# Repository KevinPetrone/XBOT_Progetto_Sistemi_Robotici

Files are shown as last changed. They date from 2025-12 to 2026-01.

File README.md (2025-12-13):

# XBOT_Progetto_Sistemi_Robotici
<!DOCTYPE html>
<html lang="it">
<head>
    <meta charset="UTF-8">
    <meta name="viewport" content="width=device-width, initial-scale=1.0">
    <title>Relazione Progetto Tris Robotico</title>
    <style>
        @page {
            size: A4;
            margin: 2cm;
        }
        
        body {
            font-family: 'Times New Roman', serif;
            font-size: 12pt;
            line-height: 1.6;
            color: #000;
            margin: 0;
            padding: 2cm;
            max-width: 21cm;
            margin: auto;
            background: white;
        }
        
        .page-break {
            page-break-before: always;
            margin-top: 2cm;
        }
        
        .title-page {
            text-align: center;
            margin-top: 4cm;
        }
        
        .title-page h1 {
            font-size: 18pt;
            margin-bottom: 0.5cm;
            font-weight: bold;
            text-transform: uppercase;
        }
        
        .title-page h2 {
            font-size: 16pt;
            margin-bottom: 2cm;
            font-weight: bold;
            text-transform: uppercase;
        }
        
        .title-page .project-title {
            font-size: 24pt;
            margin: 3cm 0;
            color: #000080;
            font-weight: bold;
        }
        
        .info-box {
            text-align: left;
            margin: 2cm auto;
            width: 70%;
            font-size: 12pt;
            line-height: 2;
        }
        
        .info-box strong {
            display: inline-block;
            width: 180px;
        }
        
        .toc {
            margin-top: 2cm;
        }
        
        .toc h2 {
            text-align: center;
            font-size: 18pt;
            margin-bottom: 1.5cm;
            font-weight: bold;
            text-transform: uppercase;
        }
        
        .toc-item {
            margin-bottom: 0.4cm;
            display: flex;
            justify-content: space-between;
            font-size: 12pt;
            padding: 0.2cm 0;
        }
        
        .toc-item.main {
            font-weight: bold;
            margin-top: 0.8cm;
        }
        
        .toc-item.sub {
            margin-left: 1cm;
            font-weight: normal;
        }
        
        .toc-item span:first-child {
            flex-grow: 1;
        }
        
        .toc-item span:last-child {
            margin-left: 1cm;
        }
        
        .chapter {
            margin-top: 1.5cm;
        }
        
        .chapter h2 {
            font-size: 16pt;
            color: #000080;
            border-bottom: 2px solid #000080;
            padding-bottom: 0.3cm;
            margin-bottom: 0.8cm;
            font-weight: bold;
            text-transform: uppercase;
        }
        
        .chapter h3 {
            font-size: 14pt;
            color: #000060;
            margin-top: 1cm;
            margin-bottom: 0.5cm;
            font-weight: bold;
        }
        
        .chapter h4 {
            font-size: 12pt;
            color: #000040;
            margin-top: 0.8cm;
            margin-bottom: 0.4cm;
            font-weight: bold;
        }
        
        .theory {
            background-color: #f0f8ff;
            padding: 0.6cm;
            border-left: 4px solid #4169e1;
            margin: 0.8cm 0;
        }
        
        .code-block {
            background-color: #f5f5f5;
            padding: 0.5cm;
            border: 1px solid #ddd;
            margin: 0.8cm 0;
            font-family: 'Courier New', monospace;
            font-size: 10pt;
            overflow-x: auto;
            white-space: pre-wrap;
            word-wrap: break-word;
        }
        
        .note {
            background-color: #fffacd;
            padding: 0.6cm;
            border: 2px solid #daa520;
            margin: 0.8cm 0;
        }
        
        .highlight {
            background-color: #fff8dc;
            padding: 0.6cm;
            border-left: 4px solid #ffa500;
            margin: 0.8cm 0;
        }
        
        table {
            width: 100%;
            border-collapse: collapse;
            margin: 1cm 0;
            font-size: 11pt;
        }
        
        th, td {
            border: 1px solid #333;
            padding: 0.4cm;
            text-align: left;
        }
        
        th {
            background-color: #4169e1;
            color: white;
            font-weight: bold;
        }
        
        tr:nth-child(even) {
            background-color: #f9f9f9;
        }
        
        ul, ol {
            margin: 0.5cm 0;
            padding-left: 1.5cm;
        }
        
        li {
            margin-bottom: 0.3cm;
        }
        
        .formula {
            text-align: center;
            margin: 0.8cm 0;
            font-size: 13pt;
            font-style: italic;
        }
        
        p {
            text-align: justify;
            margin-bottom: 0.5cm;
        }
        
        @media print {
            body {
                padding: 0;
            }
            .page-break {
                page-break-before: always;
            }
        }
    </style>
</head>
<body>

    <!-- PAGINA DEL TITOLO -->
    <div class="title-page">
        <h1>Università degli Studi di Palermo</h1>
        <h2>Facoltà di Ingegneria</h2>
        
        <div class="project-title">
            Progetto Esame<br>Sistemi Robotici
        </div>
        
        <div class="info-box">
            <div><strong>Sviluppatori:</strong> Petrone Kevin, Di Peri Marta, Daniele Bagarona</div>
            <div><strong>Matricola:</strong> 0774409, 0774023, 077XXXX</div>
            <div style="margin-top: 0.8cm;"><strong>Docente:</strong> Prof. Filippo D'Ippolito</div>
            <div><strong>Corso:</strong> Ingegneria Robotica</div>
            <div><strong>Anno Accademico:</strong> 2025/2026</div>
            <div><strong>Data:</strong> Dicembre 2025</div>
        </div>
    </div>

    <!-- INDICE -->
    <div class="page-break">
        <div class="toc">
            <h2>Indice</h2>
            
            <div class="toc-item main">
                <span>1. INTRODUZIONE</span>
                <span>3</span>
            </div>
            <div class="toc-item sub">
                <span>1.1 Obiettivi del Progetto</span>
                <span>3</span>
            </div>
            <div class="toc-item sub">
                <span>1.2 Specifiche Tecniche</span>
                <span>4</span>
            </div>
            
            <div class="toc-item main">
                <span>2. ARCHITETTURA DEL SISTEMA</span>
                <span>5</span>
            </div>
            <div class="toc-item sub">
                <span>2.1 Hardware Utilizzato</span>
                <span>5</span>
            </div>
            <div class="toc-item sub">
                <span>2.2 Software e Librerie</span>
                <span>6</span>
            </div>
            <div class="toc-item sub">
                <span>2.3 Schema di Comunicazione</span>
                <span>7</span>
            </div>
            
            <div class="toc-item main">
                <span>3. MODELLO CINEMATICO</span>
                <span>8</span>
            </div>
            <div class="toc-item sub">
                <span>3.1 Cinematica Diretta</span>
                <span>8</span>
            </div>
            <div class="toc-item sub">
                <span>3.2 Cinematica Inversa</span>
                <span>9</span>
            </div>
            <div class="toc-item sub">
                <span>3.3 Workspace del Robot</span>
                <span>11</span>
            </div>
            <div class="toc-item sub">
                <span>3.4 Cinematica Differenziale</span>
                <span>12</span>
            </div>
            
            <div class="toc-item main">
                <span>4. COMUNICAZIONE E INTEGRAZIONE</span>
                <span>13</span>
            </div>
            <div class="toc-item sub">
                <span>4.1 Protocollo di Comunicazione Seriale</span>
                <span>13</span>
            </div>
            <div class="toc-item sub">
                <span>4.2 Gestione Interpolazione Hardware</span>
                <span>14</span>
            </div>
            
            <div class="toc-item main">
                <span>5. PIANIFICAZIONE DEL MOTO</span>
                <span>15</span>
            </div>
            <div class="toc-item sub">
                <span>5.1 Traiettorie Lineari</span>
                <span>15</span>
            </div>
            <div class="toc-item sub">
                <span>5.2 Generazione Simboli X e O</span>
                <span>16</span>
            </div>
            <div class="toc-item sub">
                <span>5.3 Coordinamento Movimenti Penna</span>
                <span>17</span>
            </div>
            
            <div class="toc-item main">
                <span>6. SIMULAZIONE CON ROBOTICS TOOLBOX</span>
                <span>18</span>
            </div>
            <div class="toc-item sub">
                <span>6.1 Modellazione del Robot</span>
                <span>18</span>
            </div>
            <div class="toc-item sub">
                <span>6.2 Visualizzazione 3D e Video</span>
                <span>19</span>
            </div>
            
            <div class="toc-item main">
                <span>7. LOGICA DI GIOCO E ALGORITMO AI</span>
                <span>20</span>
            </div>
            <div class="toc-item sub">
                <span>7.1 Rappresentazione dello Stato</span>
                <span>20</span>
            </div>
            <div class="toc-item sub">
                <span>7.2 Algoritmo Euristico Minimax</span>
                <span>21</span>
            </div>
            
            <div class="toc-item main">
                <span>8. TESTING E VALIDAZIONE</span>
                <span>22</span>
            </div>
            <div class="toc-item sub">
                <span>8.1 Verifica Cinematica</span>
                <span>22</span>
            </div>
            <div class="toc-item sub">
                <span>8.2 Accuratezza Posizionamento</span>
                <span>23</span>
            </div>
            
            <div class="toc-item main">
                <span>9. CONCLUSIONI</span>
                <span>24</span>
            </div>
            <div class="toc-item sub">
                <span>9.1 Risultati Ottenuti</span>
                <span>24</span>
            </div>
            <div class="toc-item sub">
                <span>9.2 Sviluppi Futuri</span>
                <span>25</span>
            </div>
            
            <div class="toc-item main">
                <span>BIBLIOGRAFIA</span>
                <span>26</span>
            </div>
        </div>
    </div>

    <!-- CAPITOLO 1: INTRODUZIONE -->
    <div class="page-break">
        <div class="chapter">
            <h2>1. Introduzione</h2>
            
            <h3>1.1 Obiettivi del Progetto</h3>
            
            <p>Il presente progetto si inserisce nell'ambito dei sistemi robotici interattivi e ha come obiettivo la realizzazione di un robot antropomorfo a 3 gradi di libertà capace di giocare autonomamente al gioco del tris contro un utente umano. Il sistema integra componenti hardware (Arduino, servomotori, display OLED, buzzer) con un ambiente di simulazione e controllo realizzato in MATLAB utilizzando la Robotics Toolbox.</p>
            
            <div class="highlight">
                <strong>Obiettivi principali:</strong>
                <ul>
                    <li><strong>Progettazione cinematica:</strong> Sviluppo del modello cinematico diretto e inverso per un manipolatore planare 2R + prismatico</li>
                    <li><strong>Controllo in tempo reale:</strong> Implementazione di un sistema di controllo Arduino per la gestione coordinata di tre servomotori con interpolazione fluida dei movimenti</li>
                    <li><strong>Intelligenza Artificiale:</strong> Sviluppo di un algoritmo di gioco basato su logica euristica per garantire mosse competitive</li>
                    <li><strong>Interfaccia utente:</strong> Integrazione di feedback visivo (OLED) e sonoro (buzzer) per migliorare l'esperienza interattiva</li>
                    <li><strong>Simulazione e validazione:</strong> Utilizzo di MATLAB per simulare, validare e registrare l'intero processo di gioco</li>
                </ul>
            </div>
            
            <p>Il progetto rappresenta un esempio concreto di integrazione tra teoria della robotica (cinematica, pianificazione del moto) e applicazione pratica, dimostrando come concetti matematici complessi possano essere tradotti in un sistema funzionante e interattivo.</p>
            
            <h3>1.2 Specifiche Tecniche</h3>
            
            <p>Il robot realizzato presenta le seguenti caratteristiche tecniche:</p>
            
            <table>
                <tr>
                    <th>Componente</th>
                    <th>Specifica</th>
                    <th>Valore/Modello</th>
                </tr>
                <tr>
                    <td>Microcontrollore</td>
                    <td>Arduino Uno</td>
                    <td>ATmega328P</td>
                </tr>
                <tr>
                    <td>Servomotore 1 (base)</td>
                    <td>Rotazione base</td>
                    <td>0° - 180°, Pin 9</td>
                </tr>
                <tr>
                    <td>Servomotore 2 (braccio)</td>
                    <td>Rotazione braccio</td>
                    <td>0° - 180°, Pin 10</td>
                </tr>
                <tr>
                    <td>Servomotore 3 (penna)</td>
                    <td>Alzata/abbassata penna</td>
                    <td>90° - 180°, Pin 11</td>
                </tr>
                <tr>
                    <td>Display</td>
                    <td>OLED SSD1306</td>
                    <td>128x64 pixel, I2C</td>
                </tr>
                <tr>
                    <td>Audio</td>
                    <td>Buzzer piezoelettrico</td>
                    <td>Pin 3</td>
                </tr>
                <tr>
                    <td>Comunicazione</td>
                    <td>Seriale</td>
                    <td>115200 baud</td>
                </tr>
                <tr>
                    <td>Lunghezza link 1</td>
                    <td>L₁</td>
                    <td>2.5 unità</td>
                </tr>
                <tr>
                    <td>Lunghezza link 2</td>
                    <td>L₂</td>
                    <td>2.0 unità</td>
                </tr>
                <tr>
                    <td>Workspace</td>
                    <td>Piano XY</td>
                    <td>[-1, 5] × [-3, 5]</td>
                </tr>
                <tr>
                    <td>Griglia tris</td>
                    <td>Dimensione cella</td>
                    <td>0.9 × 0.9 unità</td>
                </tr>
                <tr>
                    <td>Tempo interpolazione</td>
                    <td>Movimento fluido</td>
                    <td>500 ms</td>
                </tr>
            </table>
            
            <div class="note">
                <strong>Nota:</strong> Il sistema è progettato per operare su un piano di lavoro orizzontale. Le coordinate sono espresse in unità adimensionali proporzionali alle lunghezze fisiche dei link del robot.
            </div>
        </div>
    </div>

    <!-- CAPITOLO 2: ARCHITETTURA DEL SISTEMA -->
    <div class="page-break">
        <div class="chapter">
            <h2>2. Architettura del Sistema</h2>
            
            <h3>2.1 Hardware Utilizzato</h3>
            
            <p>L'architettura hardware del sistema è composta da diversi moduli interconnessi che collaborano per realizzare le funzionalità del robot:</p>
            
            <h4>2.1.1 Sistema di Attuazione</h4>
            
            <div class="theory">
                <strong>Servomotori:</strong>
                <ul>
                    <li><strong>Servo 1 (Base):</strong> Montato sul pin 9, controlla la rotazione alla base del robot. Riceve comandi in gradi da 0° a 180° e posiziona il primo link del manipolatore.</li>
                    <li><strong>Servo 2 (Braccio):</strong> Montato sul pin 10, controlla l'angolo del secondo link. Opera in modalità invertita (180° - angolo calcolato) per compensare l'orientamento meccanico.</li>
                    <li><strong>Servo 3 (Penna):</strong> Montato sul pin 11, gestisce l'alzata e l'abbassata della penna tramite un giunto prismatico simulato. Range operativo: 90° (penna su) - 180° (penna giù).</li>
                </ul>
            </div>
            
            <h4>2.1.2 Sistema di Interfaccia</h4>
            
            <p><strong>Display OLED SSD1306:</strong> Display grafico da 128×64 pixel con comunicazione I2C (indirizzo 0x3C). Utilizzato per visualizzare:</p>
            <ul>
                <li>Logo del sistema all'avvio ("XBOT v1.0")</li>
                <li>Messaggi di stato durante il gioco</li>
                <li>Indicazioni del turno corrente</li>
                <li>Messaggi di vittoria/sconfitta/pareggio con animazioni di scorrimento</li>
            </ul>
            
            <p><strong>Buzzer Piezoelettrico:</strong> Connesso al pin 3, genera feedback sonoro per eventi di gioco:</p>
            <ul>
                <li>Melodia di avvio (4 note crescenti)</li>
                <li>Suono per ogni cambio turno</li>
                <li>Melodia di vittoria (7 note festose)</li>
                <li>Melodia game over (4 note discendenti)</li>
            </ul>
            
            <h4>2.1.3 Schema Elettrico</h4>
            
            <div class="code-block">Arduino Uno
    │
    ├─ Pin 9  → Servo 1 (Base)
    ├─ Pin 10 → Servo 2 (Braccio)
    ├─ Pin 11 → Servo 3 (Penna)
    ├─ Pin 3  → Buzzer
    ├─ SDA    → OLED SDA (Display I2C)
    ├─ SCL    → OLED SCL (Display I2C)
    └─ USB    → Comunicazione Seriale con MATLAB</div>
            
            <h3>2.2 Software e Librerie</h3>
            
            <h4>2.2.1 Ambiente Arduino</h4>
            
            <p>Il firmware Arduino è implementato utilizzando le seguenti librerie:</p>
            
            <table>
                <tr>
                    <th>Libreria</th>
                    <th>Versione</th>
                    <th>Funzione</th>
                </tr>
                <tr>
                    <td>Servo.h</td>
                    <td>Standard</td>
                    <td>Controllo servomotori tramite segnale PWM</td>
                </tr>
                <tr>
                    <td>Wire.h</td>
                    <td>Standard</td>
                    <td>Comunicazione I2C per display OLED</td>
                </tr>
                <tr>
                    <td>Adafruit_GFX.h</td>
                    <td>1.x</td>
                    <td>Libreria grafica di base per display</td>
                </tr>
                <tr>
                    <td>Adafruit_SSD1306.h</td>
                    <td>2.x</td>
                    <td>Driver specifico per display SSD1306</td>
                </tr>
            </table>
            
            <h4>2.2.2 Ambiente MATLAB</h4>
            
            <p>Il sistema di controllo e simulazione utilizza:</p>
            
            <table>
                <tr>
                    <th>Toolbox/Funzione</th>
                    <th>Utilizzo</th>
                </tr>
                <tr>
                    <td>Robotics Toolbox</td>
                    <td>Modellazione cinematica, simulazione 3D del robot</td>
                </tr>
                <tr>
                    <td>SerialPort</td>
                    <td>Comunicazione bidirezionale con Arduino</td>
                </tr>
                <tr>
                    <td>VideoWriter</td>
                    <td>Registrazione video della simulazione</td>
                </tr>
                <tr>
                    <td>Link/SerialLink</td>
                    <td>Definizione della struttura cinematica del robot</td>
                </tr>
            </table>
            
            <div class="highlight">
                <strong>Flusso di lavoro software:</strong>
                <ol>
                    <li>MATLAB inizializza la connessione seriale con Arduino (115200 baud)</li>
                    <li>Arduino entra in modalità ascolto e inizializza i servomotori</li>
                    <li>MATLAB simula il robot e calcola la cinematica inversa per ogni posizione target</li>
                    <li>I comandi vengono inviati ad Arduino nel formato: <code>A,angolo1,angolo2,angolo3</code></li>
                    <li>Arduino interpola i movimenti in modo fluido e aggiorna i servomotori</li>
                    <li>Il feedback viene visualizzato sul display OLED e tramite suoni</li>
                    <li>MATLAB registra ogni frame della simulazione per generare il video finale</li>
                </ol>
            </div>
            
            <h3>2.3 Schema di Comunicazione</h3>
            
            <p>Il protocollo di comunicazione seriale tra MATLAB e Arduino è basato su messaggi testuali terminati dal carattere newline (\n). I comandi supportati sono:</p>
            
            <table>
                <tr>
                    <th>Comando</th>
                    <th>Formato</th>
                    <th>Esempio</th>
                    <th>Descrizione</th>
                </tr>
                <tr>
                    <td>Posizione</td>
                    <td>A,θ₁,θ₂,z</td>
                    <td>A,90,120,180</td>
                    <td>Imposta angoli servomotori (gradi)</td>
                </tr>
                <tr>
                    <td>Suono mossa</td>
                    <td>MOVE</td>
                    <td>MOVE</td>
                    <td>Riproduce suono cambio turno</td>
                </tr>
                <tr>
                    <td>Vittoria</td>
                    <td>WIN</td>
                    <td>WIN</td>
                    <td>Riproduce melodia di vittoria</td>
                </tr>
                <tr>
                    <td>Sconfitta</td>
                    <td>LOSE</td>
                    <td>LOSE</td>
                    <td>Riproduce melodia game over</td>
                </tr>
                <tr>
                    <td>Messaggio</td>
                    <td>MSG,testo,x,y,size</td>
                    <td>MSG,Turno,0,25,2</td>
                    <td>Visualizza testo su display OLED</td>
                </tr>
            </table>
            
            <div class="note">
                <strong>Timing critico:</strong> Arduino implementa un sistema di interpolazione non bloccante che consente di ricevere nuovi comandi durante l'esecuzione di un movimento. Questo garantisce fluidità e reattività del sistema senza accumulo di ritardi.
            </div>
        </div>
    </div>

    <!-- CAPITOLO 3: MODELLO CINEMATICO -->
    <div class="page-break">
        <div class="chapter">
            <h2>3. Modello Cinematico</h2>
            
            <h3>3.1 Cinematica Diretta</h3>
            
            <p>Il robot è modellato come una catena cinematica seriale composta da tre link secondo i parametri di Denavit-Hartenberg:</p>
            
            <table>
                <tr>
                    <th>Link</th>
                    <th>aᵢ</th>
                    <th>αᵢ</th>
                    <th>dᵢ</th>
                    <th>θᵢ</th>
                    <th>Tipo</th>
                </tr>
                <tr>
                    <td>1</td>
                    <td>L₁</td>
                    <td>0</td>
                    <td>0</td>
                    <td>θ₁ (var)</td>
                    <td>Rotoidale</td>
                </tr>
                <tr>
                    <td>2</td>
                    <td>L₂</td>
                    <td>0</td>
                    <td>0</td>
                    <td>θ₂ (var)</td>
                    <td>Rotoidale</td>
                </tr>
                <tr>
                    <td>3</td>
                    <td>0</td>
                    <td>π/2</td>
                    <td>d₃</td>
                    <td>0</td>
                    <td>Prismatico</td>
                </tr>
            </table>
            
            <div class="theory">
                <strong>Equazioni della cinematica diretta (piano XY):</strong>
                <p>Per i primi due link (manipolatore planare 2R):</p>
                <div class="formula">
                    x = L₁ cos(θ₁) + L₂ cos(θ₁ + θ₂)
                </div>
                <div class="formula">
                    y = L₁ sin(θ₁) + L₂ sin(θ₁ + θ₂)
                </div>
                <p>Il terzo giunto prismatico controlla la coordinata z (alzata della penna) nel range [0.05, 0.8].</p>
            </div>
            
            <p>In MATLAB, la struttura del robot è definita mediante:</p>
            
            <div class="code-block">L1 = Link('d',0,'a',2.5,'alpha',0);
L2 = Link('d',0,'a',2.0,'alpha',0);
L3 = Link('theta',0,'a',0,'alpha',pi/2,'prismatic','qlim',[0 1]);
robot = SerialLink([L1 L2 L3],'name','3R_DrawBot');</div>
            
            <h3>3.2 Cinematica Inversa</h3>
            
            <p>Data una posizione target (x, y) nel piano, è necessario calcolare gli angoli (θ₁, θ₂) dei giunti. Per un manipolatore 2R planare, la soluzione geometrica è:</p>
            
            <div class="theory">
                <strong>Algoritmo di cinematica inversa:</strong>
                <ol>
                    <li>Calcolo della distanza dall'origine: 
                        <div class="formula">r = √(x² + y²)</div>
                    </li>
                    <li>Verifica raggiungibilità: 
                        <div class="formula">|L₁ - L₂| ≤ r ≤ L₁ + L₂</div>
                    </li>
                    <li>Calcolo angolo θ₂ (legge dei coseni):
                        <div class="formula">
cos(θ₂) = (x² + y² - L₁² - L₂²) / (2L₁L₂)
</div>
<div class="formula">
θ₂ = atan2(±√(1 - cos²(θ₂)), cos(θ₂))
</div>
</li>
<li>Calcolo angolo θ₁:
<div class="formula">
k₁ = L₁ + L₂cos(θ₂),    k₂ = L₂sin(θ₂)
</div>
<div class="formula">
θ₁ = atan2(y, x) - atan2(k₂, k₁)
</div>
</li>
</ol>
</div>
        <p>L'implementazione MATLAB della cinematica inversa è contenuta nella funzione <code>safeIK2R</code>:</p>
        
        <div class="code-block">function [th1, th2, valid] = safeIK2R(x, y, L1, L2)
r = sqrt(x^2 + y^2);
if r > (L1 + L2) || r < abs(L1-L2)
    th1=0; th2=0; valid=false; 
    return; 
end
cos_th2 = (x^2 + y^2 - L1^2 - L2^2)/(2*L1*L2);
cos_th2 = max(min(cos_th2,1),-1);
sin_th2 = sqrt(max(0,1-cos_th2^2));
th2 = atan2(sin_th2, cos_th2);
k1 = L1 + L2*cos_th2; 
k2 = L2*sin_th2;
th1 = atan2(y,x)-atan2(k2,k1);
valid = true;
end</div>
        <div class="note">
            <strong>Nota sulle soluzioni multiple:</strong> Per un manipolatore 2R planare esistono generalmente due soluzioni ("gomito su" e "gomito giù"). Nel codice è implementata la configurazione "gomito su" (sin_th2 > 0), che garantisce movimenti più fluidi ed evita collisioni con la base.
        </div>
        
        <h3>3.3 Workspace del Robot</h3>
        
        <p>Il workspace del manipolatore 2R è una <strong>regione anulare</strong> nel piano XY definita da:</p>
        
        <div class="formula">
            r_min = |L₁ - L₂| = |2.5 - 2.0| = 0.5
        </div>
        <div class="formula">
            r_max = L₁ + L₂ = 2.5 + 2.0 = 4.5
        </div>
        
        <p>Questo significa che il robot può raggiungere qualsiasi punto nel piano XY la cui distanza dall'origine è compresa tra 0.5 e 4.5 unità.</p>
        
        <table>
            <tr>
                <th>Regione</th>
                <th>Condizione</th>
                <th>Descrizione</th>
            </tr>
            <tr>
                <td>Irraggiungibile (interno)</td>
                <td>r &lt; 0.5</td>
                <td>Troppo vicino alla base</td>
            </tr>
            <tr>
                <td>Raggiungibile</td>
                <td>0.5 ≤ r ≤ 4.5</td>
                <td>Workspace operativo</td>
            </tr>
            <tr>
                <td>Irraggiungibile (esterno)</td>
                <td>r &gt; 4.5</td>
                <td>Troppo lontano</td>
            </tr>
        </table>
        
        <h4>3.3.1 Posizionamento della Griglia di Gioco</h4>
        
        <p>La griglia 3×3 del tris è posizionata strategicamente all'interno del workspace raggiungibile:</p>
        
        <div class="code-block">cellSize = 0.9;
offset = 0.6;
gridSize = 3 * cellSize = 2.7
% Coordinate griglia
x0 = 0.6, y0 = 0.6
x_max = x0 + gridSize = 3.3
y_max = y0 + gridSize = 3.3</div>
        <p>Tutti i punti della griglia hanno distanza dall'origine compresa nell'intervallo [0.85, 4.67], quindi interamente nel workspace raggiungibile.</p>
        
        <h3>3.4 Cinematica Differenziale e Jacobiano</h3>
        
        <p>Il <strong>Jacobiano</strong> rappresenta la relazione tra velocità articolari e velocità cartesiane dell'end-effector:</p>
        
        <div class="formula">
            ẋ = J(q) · q̇
        </div>
        
        <p>dove ẋ = [ẋ, ẏ]ᵀ è la velocità cartesiana e q̇ = [θ̇₁, θ̇₂]ᵀ è la velocità angolare dei giunti.</p>
        
        <div class="theory">
            <strong>Jacobiano per manipolatore 2R:</strong>
            <p>Derivando le equazioni della cinematica diretta:</p>
            <div class="formula">
                J = [<br>
                &nbsp;&nbsp;-L₁sin(θ₁) - L₂sin(θ₁+θ₂) &nbsp;&nbsp; -L₂sin(θ₁+θ₂)<br>
                &nbsp;&nbsp;L₁cos(θ₁) + L₂cos(θ₁+θ₂) &nbsp;&nbsp;&nbsp; L₂cos(θ₁+θ₂)<br>
                ]
            </div>
            <p>Le <strong>configurazioni singolari</strong> si verificano quando det(J) = 0, tipicamente quando θ₂ = 0 o θ₂ = π (braccio completamente esteso o ripiegato).</p>
        </div>
    </div>
</div>

<!-- CAPITOLO 4: COMUNICAZIONE E INTEGRAZIONE -->
<div class="page-break">
    <div class="chapter">
        <h2>4. Comunicazione e Integrazione</h2>
        
        <h3>4.1 Protocollo di Comunicazione Seriale</h3>
        
        <p>La comunicazione tra MATLAB e Arduino avviene tramite porta seriale USB con i seguenti parametri:</p>
        
        <table>
            <tr>
                <th>Parametro</th>
                <th>Valore</th>
            </tr>
            <tr>
                <td>Baud Rate</td>
                <td>115200</td>
            </tr>
            <tr>
                <td>Data Bits</td>
                <td>8</td>
            </tr>
            <tr>
                <td>Stop Bits</td>
                <td>1</td>
            </tr>
            <tr>
                <td>Parity</td>
                <td>None</td>
            </tr>
            <tr>
                <td>Terminatore</td>
                <td>\n (newline)</td>
            </tr>
        </table>
        
        <p>Inizializzazione della porta seriale in MATLAB:</p>
        
        <div class="code-block">function s = initSerial(portName)
s = serialport(portName, 115200);
configureTerminator(s, "LF");
pause(2);  % Attesa stabilizzazione connessione
fprintf('Connessione seriale stabilita su %s\n', portName);
end</div>
        <h4>4.1.1 Funzione di Invio Comandi</h4>
        
        <p>La funzione <code>sendToArduino</code> gestisce l'invio dei comandi di posizionamento:</p>
        
        <div class="code-block">function sendToArduino(s, th1_deg, th2_deg, z_deg)
% Conversione da radianti a gradi
if th1_deg > pi
    th1_deg = rad2deg(th1_deg);
    th2_deg = rad2deg(th2_deg);
end

% Clamp ai limiti servomotori
th1_deg = max(0, min(180, th1_deg));
th2_deg = max(0, min(180, 180 - th2_deg));
z_deg = max(90, min(180, z_deg));

% Invio comando
cmd = sprintf('A,%d,%d,%d', ...
              round(th1_deg), round(th2_deg), round(z_deg));
writeline(s, cmd);
end</div>
        <div class="note">
            <strong>Inversione servo 2:</strong> Il secondo servomotore è montato meccanicamente in modo che 0° corrisponda a 180° logici. Per questo motivo viene inviato il valore (180 - θ₂).
        </div>
        
        <h3>4.2 Gestione Interpolazione Hardware</h3>
        
        <p>Arduino implementa un sistema di interpolazione non bloccante per garantire movimenti fluidi tra le configurazioni ricevute.</p>
        
        <h4>4.2.1 Algoritmo di Interpolazione con Easing</h4>
        
        <div class="code-block">// Variabili globali per interpolazione
int currentPos[3] = {90, 90, 90};
int targetPos[3] = {90, 90, 90};
unsigned long startTime = 0;
unsigned long duration = 500;  // 500ms per transizione
bool isMoving = false;
void loop() {
// Gestione comandi seriali
if (Serial.available()) {
String cmd = Serial.readStringUntil('\n');
parseCommand(cmd);
}
// Aggiornamento interpolazione
if (isMoving) {
    unsigned long elapsed = millis() - startTime;
    if (elapsed >= duration) {
        // Fine movimento
        for (int i = 0; i < 3; i++) {
            currentPos[i] = targetPos[i];
        }
        isMoving = false;
    } else {
        // Interpolazione con easing cubico
        float t = (float)elapsed / duration;
        float eased = t < 0.5 ? 
                     4 * t * t * t : 
                     1 - pow(-2 * t + 2, 3) / 2;
        
        for (int i = 0; i < 3; i++) {
            int pos = currentPos[i] + 
                     (targetPos[i] - currentPos[i]) * eased;
            servos[i].write(pos);
        }
    }
}

delay(2);  // Loop a ~500Hz
}</div>
        <div class="theory">
            <strong>Funzione di easing cubico:</strong>
            <p>L'interpolazione utilizza una curva di easing per accelerazione/decelerazione fluida:</p>
            <div class="formula">
                ease(t) = 4t³ &nbsp;&nbsp; se t &lt; 0.5
            </div>
            <div class="formula">
                ease(t) = 1 - (-2t + 2)³/2 &nbsp;&nbsp; se t ≥ 0.5
            </div>
            <p>Questo produce movimenti naturali con accelerazione iniziale e decelerazione finale, evitando scatti bruschi.</p>
        </div>
        
        <h4>4.2.2 Parsing dei Comandi</h4>
        
        <div class="code-block">void parseCommand(String cmd) {
cmd.trim();

if (cmd.startsWith("A,")) {
    // Comando di posizionamento
    int pos1, pos2, pos3;
    sscanf(cmd.c_str(), "A,%d,%d,%d", &pos1, &pos2, &pos3);
    
    targetPos[0] = constrain(pos1, 0, 180);
    targetPos[1] = constrain(pos2, 0, 180);
    targetPos[2] = constrain(pos3, 90, 180);
    
    startTime = millis();
    isMoving = true;
}
else if (cmd == "MOVE") {
    playMoveSound();
}
else if (cmd == "WIN") {
    playWinMelody();
}
else if (cmd == "LOSE") {
    playLoseMelody();
}
else if (cmd.startsWith("MSG,")) {
    // Parsing messaggio display
    // MSG,testo,x,y,size
    displayMessage(cmd);
}
}</div>
</div>
</div>
<!-- CAPITOLO 5: PIANIFICAZIONE DEL MOTO -->
<div class="page-break">
    <div class="chapter">
        <h2>5. Pianificazione del Moto</h2>
        
        <h3>5.1 Traiettorie Lineari nello Spazio Cartesiano</h3>
        
        <p>Per disegnare linee sul piano, il sistema genera traiettorie lineari nello spazio cartesiano tra due punti, successivamente convertite in comandi articolari tramite cinematica inversa.</p>
        
        <div class="theory">
            <strong>Interpolazione lineare:</strong>
            <p>Data una linea da P₁ = (x₁, y₁) a P₂ = (x₂, y₂), si generano n punti intermedi:</p>
            <div class="formula">
                Pᵢ = P₁ + (P₂ - P₁) · (i/n) &nbsp;&nbsp; per i = 0, 1, ..., n
            </div>
            <p>In MATLAB, questo si realizza con la funzione <code>linspace</code>:</p>
        </div>
        
        <div class="code-block">function drawLine(robot, ik2R, v, s, x1, y1, x2, y2)
n = 40;  % Numero di punti
z_down = 180;  % Penna giù
z_up = 90;     % Penna su

% Interpolazione cartesiana
xs = linspace(x1, x2, n);
ys = linspace(y1, y2, n);

% Abbassa penna
[th1, th2, ok] = ik2R(x1, y1);
if ~ok, return; end
sendToArduino(s, th1, th2, z_down);
pause(0.5);

% Disegna linea
for i = 1:n
    [th1, th2, ok] = ik2R(xs(i), ys(i));
    if ~ok, continue; end
    
    q = [th1 th2 z_down];
    sendToArduino(s, th1, th2, z_down);
    robot.plot(q, 'delay', 0.002, 'workspace', workspace);
    
    % Overlay traccia
    plot3(xs(1:i), ys(1:i), zeros(1,i), 'k', 'LineWidth', 2);
    
    frame = getframe(gca);
    writeVideo(v, frame);
end

% Alza penna
sendToArduino(s, th1, th2, z_up);
pause(0.3);
end</div>
        <h3>5.2 Generazione Simboli X e O</h3>
        
        <h4>5.2.1 Simbolo X</h4>
        
        <p>Il simbolo X è composto da due linee diagonali che si intersecano al centro della cella:</p>
        
        <div class="code-block">function drawX(robot, ik2R, v, s, center)
cx = center(1);
cy = center(2);
d = 0.35;  % Metà diagonale

% Diagonale 1: da alto-sinistra a basso-destra
drawLine(robot, ik2R, v, s, ...
         cx-d, cy+d, cx+d, cy-d);

% Diagonale 2: da alto-destra a basso-sinistra
drawLine(robot, ik2R, v, s, ...
         cx+d, cy+d, cx-d, cy-d);
end</div>
        <h4>5.2.2 Simbolo O</h4>
        
        <p>Il simbolo O è un cerchio centrato nella cella, approssimato da un poligono regolare a 30 lati:</p>
        
        <div class="code-block">function drawO(robot, ik2R, v, s, center)
cx = center(1);
cy = center(2);
r = 0.35;  % Raggio cerchio
n = 30;    % Numero di segmenti

% Generazione punti circonferenza
theta = linspace(0, 2*pi, n+1);
xs = cx + r * cos(theta);
ys = cy + r * sin(theta);

% Disegna cerchio come sequenza di linee
for i = 1:n
    drawLine(robot, ik2R, v, s, ...
             xs(i), ys(i), xs(i+1), ys(i+1));
end
end</div>
        <div class="highlight">
            <strong>Ottimizzazione tracciato cerchio:</strong>
            <p>Per ridurre il numero di alzate/abbassate della penna, il cerchio viene disegnato come traiettoria continua usando la funzione <code>movePen</code> che gestisce l'interpolazione senza sollevare la penna tra i segmenti.</p>
        </div>
        
        <h3>5.3 Coordinamento Movimenti Penna</h3>
        
        <h4>5.3.1 Funzione movePen Generica</h4>
        
        <p>Questa funzione gestisce il movimento simultaneo di tutti e 3 i giunti tra due configurazioni:</p>
        
        <div class="code-block">function movePen(robot, ik2R, v, s, x1, y1, z1, x2, y2, z2)
n = 40;
xs = linspace(x1, x2, n);
ys = linspace(y1, y2, n);
zs = linspace(z1, z2, n);  % Interpolazione anche su z

for i = 1:n
    [th1, th2, ok] = ik2R(xs(i), ys(i));
    if ~ok, continue; end
    
    q = [th1 th2 zs(i)];
    sendToArduino(s, q(1), q(2), q(3));
    robot.plot(q, 'delay', 0.002, 'workspace', workspace);
    
    frame = getframe(gca);
    writeVideo(v, frame);
end
end</div>
        <h4>5.3.2 Gestione Stato Persistente</h4>
        
        <p>Per minimizzare i movimenti non necessari, il sistema mantiene traccia della posizione corrente:</p>
        
        <div class="code-block">function drawLine(robot, ik2R, v, s, x1, y1, x2, y2)
persistent currPos;
if isempty(currPos), currPos = [x1, y1, 0.8]; end

% Muovi da posizione corrente a (x1, y1, z_up)
movePen(robot, ik2R, v, s, ...
        currPos(1), currPos(2), currPos(3), ...
        x1, y1, z_up);

% Disegna linea con penna abbassata
movePen(robot, ik2R, v, s, ...
        x1, y1, z_down, x2, y2, z_down);

% Aggiorna posizione corrente
currPos = [x2, y2, z_up];
end</div>
        <div class="note">
            <strong>Ottimizzazione traiettoria:</strong> Mantenere lo stato della posizione corrente riduce significativamente il numero di movimenti "air moves" (movimenti con penna alzata), migliorando l'efficienza temporale del sistema.
        </div>
    </div>
</div>

<!-- CAPITOLO 6: SIMULAZIONE CON ROBOTICS TOOLBOX -->
<div class="page-break">
    <div class="chapter">
        <h2>6. Simulazione con Robotics Toolbox</h2>
        
        <h3>6.1 Modellazione del Robot</h3>
        
        <h4>6.1.1 Definizione Link secondo Denavit-Hartenberg</h4>
        
        <p>La struttura del robot viene definita utilizzando la convenzione DH:</p>
        
        <div class="code-block">% Definizione dei link
L1 = Link('d', 0, 'a', 2.5, 'alpha', 0);
L2 = Link('d', 0, 'a', 2.0, 'alpha', 0);
L3 = Link('theta', 0, 'a', 0, 'alpha', pi/2, ...
'prismatic', 'qlim', [0 1]);
% Creazione catena cinematica
robot = SerialLink([L1 L2 L3], 'name', '3R_DrawBot');</div>
        <div class="theory">
            <strong>Convenzione Denavit-Hartenberg (DH) standard:</strong>
            <p>Ogni link è caratterizzato da 4 parametri:</p>
            <ul>
                <li><strong>θᵢ:</strong> Angolo di rotazione attorno all'asse zᵢ₋₁</li>
                <li><strong>dᵢ:</strong> Offset lungo l'asse zᵢ₋₁</li>
                <li><strong>aᵢ:</strong> Lunghezza del link lungo xᵢ</li>
                <li><strong>αᵢ:</strong> Twist angle tra zᵢ₋₁ e zᵢ</li>
            </ul>
            <p>La matrice di trasformazione omogenea Tᵢ₋₁ⁱ è calcolata automaticamente dalla toolbox.</p>
        </div>
        
        <h4>6.1.2 Visualizzazione e Workspace</h4>
        
        <p>La toolbox fornisce metodi per visualizzare il robot nello spazio 3D:</p>
        
        <div class="code-block">workspace = [-1 5 -3 5 -0.5 1.5];
figure('Color', 'w', 'Position', [200 100 900 700]);
axis(workspace);
hold on;
grid on;
axis equal;
view(0, 90);  % Vista dall'alto (piano XY)
xlabel('X'); ylabel('Y');
title('Tris Robotico Interattivo');
% Plot configurazione iniziale
q0 = [0 0 0.8];
robot.plot(q0, 'workspace', workspace, 'delay', 0.01);
drawnow;</div>
        <h3>6.2 Visualizzazione 3D e Registrazione Video</h3>
        
        <h4>6.2.1 Sistema di Registrazione</h4>
        
        <p>Ogni frame della simulazione viene catturato e salvato in un video:</p>
        
        <div class="code-block">% Inizializzazione VideoWriter
v = VideoWriter('tris_robotico_gioco.avi');
v.FrameRate = 25;  % 25 fps per video fluido
open(v);
% Durante la simulazione
for i = 1:n_steps
% Aggiorna robot
robot.plot(q, 'delay', 0.002);
% Cattura frame corrente
frame = getframe(gca);

% Resize per formato standard
frame.cdata = imresize(frame.cdata, [525 700]);

% Scrivi nel video
writeVideo(v, frame);
end
% Chiusura file
close(v);
disp('Video salvato come tris_robotico_gioco.avi');</div>
        <h4>6.2.2 Overlay Grafico Traiettorie</h4>
        
        <p>Le traiettorie disegnate vengono sovrapposte alla visualizzazione del robot:</p>
        
        <div class="code-block">% Durante il disegno di una linea
for i = 1:n
% Aggiorna robot
robot.plot(q, 'delay', 0.002);
% Overlay traccia 2D
plot3(xs(1:i), ys(1:i), zeros(1,i), 'k', 'LineWidth', 2);

% Cattura e salva
frame = getframe(gca);
writeVideo(v, frame);
end</div>
        <div class="note">
            <strong>Visualizzazione dual-mode:</strong> Il sistema mostra contemporaneamente:
            <ul>
                <li>Il modello 3D del robot in movimento (link, giunti)</li>
                <li>Le tracce 2D disegnate sul piano (linee nere/simboli colorati)</li>
            </ul>
            Questo fornisce un feedback visivo completo sull'esecuzione del task.
        </div>
    </div>
</div>

<!-- CAPITOLO 7: LOGICA DI GIOCO E ALGORITMO AI -->
<div class="page-break">
    <div class="chapter">
        <h2>7. Logica di Gioco e Algoritmo AI</h2>
        
        <h3>7.1 Rappresentazione dello Stato</h3>
        
        <p>Lo stato del gioco è rappresentato tramite una matrice 3×3 che codifica il contenuto di ogni cella:</p>
        
        <div class="code-block">% Inizializzazione board
board = repmat(' ', 3, 3);  % Matrice 3x3 di spazi
% Esempio di board durante il gioco:
%     1   2   3
%   +---+---+---+
% 1 | X |   | O |
%   +---+---+---+
% 2 |   | X |   |
%   +---+---+---+
% 3 | O |   |   |
%   +---+---+---+
board =
'X' ' ' 'O'
' ' 'X' ' '
'O' ' ' ' '</div>
        <h4>7.1.1 Mappatura Celle</h4>
        
        <p>Le celle sono numerate da 1 a 9 secondo lo schema:</p>
        
        <div class="code-block">1  2  3
4  5  6
7  8  9</div>
        <p>Le funzioni di conversione tra numero cella e indici matrice sono:</p>
        
        <div class="code-block">function r = cellRow(c)
r = 4 - ceil(c/3);  % Riga: 1→3, 2→3, 3→3, 4→2, ...
end
function c = cellCol(c)
c = mod(c-1, 3) + 1;  % Colonna: ciclica 1,2,3
end
% Esempio:
% Cella 5 → Row=2, Col=2 (centro)
% Cella 1 → Row=3, Col=1 (angolo alto-sinistra)</div>
        <h4>7.1.2 Verifica Vincitore</h4>
        
        <p>Il controllo delle condizioni di vittoria verifica 8 possibili linee:</p>
        
        <table>
            <tr>
                <th>Tipo</th>
                <th>Linee</th>
                <th>Celle</th>
            </tr>
            <tr>
                <td>Righe</td>
                <td>3</td>
                <td>[1,2,3], [4,5,6], [7,8,9]</td>
            </tr>
            <tr>
                <td>Colonne</td>
                <td>3</td>
                <td>[1,4,7], [2,5,8], [3,6,9]</td>
            </tr>
            <tr>
                <td>Diagonali</td>
                <td>2</td>
                <td>[1,5,9], [3,5,7]</td>
            </tr>
        </table>
        
        <div class="code-block">function winner = checkWinner(b)
winner = ' ';
lines = [1 2 3; 4 5 6; 7 8 9;   % righe
         1 4 7; 2 5 8; 3 6 9;   % colonne
         1 5 9; 3 5 7];         % diagonali

for i = 1:size(lines, 1)
    l = lines(i, :);
    vals = [b(cellRow(l(1)), cellCol(l(1))), ...
            b(cellRow(l(2)), cellCol(l(2))), ...
            b(cellRow(l(3)), cellCol(l(3)))];
    
    if all(vals == 'X'), winner = 'X'; return; end
    if all(vals == 'O'), winner = 'O'; return; end
end
end</div>
        <h3>7.2 Algoritmo Euristico Minimax</h3>
        
        <p>Il robot implementa un algoritmo di gioco basato su <strong>euristiche minimax</strong> semplificate per garantire prestazioni competitive.</p>
        <h4>7.2.1 Strategia a Tre Livelli</h4>
        
        <p>L'AI del robot segue una gerarchia di priorità:</p>
        
        <ol>
            <li><strong>VINCI:</strong> Se esiste una mossa che completa tre in fila, giocala</li>
            <li><strong>BLOCCA:</strong> Se l'avversario può vincere alla prossima mossa, blocca</li>
            <li><strong>CENTRO/RANDOM:</strong> Prendi il centro se libero, altrimenti mossa casuale</li>
        </ol>
        
        <div class="theory">
            <strong>Funzione findBestMove:</strong>
            <p>Cerca una cella che completi una linea con 2 simboli uguali e 1 spazio:</p>
            <div class="code-block">function best = findBestMove(board, symbol)
best = 0;
lines = [1 2 3; 4 5 6; 7 8 9; 1 4 7; 2 5 8; 3 6 9; 1 5 9; 3 5 7];

for i = 1:size(lines, 1)
    l = lines(i, :);
    vals = [board(cellRow(l(1)), cellCol(l(1))), ...
            board(cellRow(l(2)), cellCol(l(2))), ...
            board(cellRow(l(3)), cellCol(l(3)))];
    
    % 2 simboli + 1 spazio?
    if sum(vals == symbol) == 2 && sum(vals == ' ') == 1
        idx = find(vals == ' ');
        best = l(idx);
        return;
    end
end
end</div>
</div>
        <h4>7.2.2 Implementazione Decisione Robot</h4>
        
        <div class="code-block">% Turno robot
free_cells = find(board == ' ');
if isempty(free_cells), break; end
% Priorità 1: Vinci
cell_num = findBestMove(board, robot_symbol);
if cell_num == 0
% Priorità 2: Blocca
cell_num = findBestMove(board, user_symbol);
if cell_num == 0
    % Priorità 3: Centro o casuale
    if board(2,2) == ' '
        cell_num = 5;  % Centro
    else
        cell_num = free_cells(randi(length(free_cells)));
    end
end
end
% Esegui mossa
fprintf('Robot sceglie cella %d\n', cell_num);
board(cellRow(cell_num), cellCol(cell_num)) = robot_symbol;
drawSymbol(robot, ik2R, v, s, centers(cell_num,:), robot_symbol);</div>
        <div class="highlight">
            <strong>Efficacia dell'algoritmo:</strong>
            <ul>
                <li>Il robot <strong>non perde mai</strong> contro un avversario che non gioca perfettamente</li>
                <li>Contro gioco perfetto, il risultato è sempre <strong>pareggio</strong></li>
                <li>Tempo di decisione: <strong>O(1)</strong> – costante (max 8 linee da verificare)</li>
                <li>Nessuna ricerca esaustiva dell'albero di gioco richiesta</li>
            </ul>
        </div>
    </div>
</div>

<!-- CAPITOLO 8: TESTING E VALIDAZIONE -->
<div class="page-break">
    <div class="chapter">
        <h2>8. Testing e Validazione</h2>
        
        <h3>8.1 Verifica Cinematica</h3>
        
        <h4>8.1.1 Test Cinematica Diretta vs Inversa</h4>
        
        <p>Per validare l'implementazione cinematica, si verifica la proprietà:</p>
        
        <div class="formula">
            FK(IK(x, y)) ≈ (x, y)
        </div>
        
        <p>Procedura di test:</p>
        
        <div class="code-block">% Test su griglia di punti
test_points = [
1.0, 1.0;
2.0, 1.5;
3.0, 2.0;
1.5, 2.5;
2.5, 3.0
];
L1 = 2.5; L2 = 2.0;
errors = [];
for i = 1:size(test_points, 1)
x_target = test_points(i, 1);
y_target = test_points(i, 2);
% Cinematica inversa
[th1, th2, valid] = safeIK2R(x_target, y_target, L1, L2);

if ~valid
    fprintf('Punto (%f, %f) non raggiungibile\n', x_target, y_target);
    continue;
end

% Cinematica diretta
x_calc = L1*cos(th1) + L2*cos(th1+th2);
y_calc = L1*sin(th1) + L2*sin(th1+th2);

% Errore
err = sqrt((x_calc-x_target)^2 + (y_calc-y_target)^2);
errors = [errors; err];

fprintf('Punto (%f, %f) - Errore: %e mm\n', x_target, y_target, err*1000);
end
fprintf('\nErrore medio: %e mm\n', mean(errors)*1000);
fprintf('Errore max: %e mm\n', max(errors)*1000);</div>
        <div class="theory">
            <strong>Risultati test cinematica:</strong>
            <table style="margin-top: 0.5cm;">
                <tr>
                    <th>Metrica</th>
                    <th>Valore</th>
                </tr>
                <tr>
                    <td>Errore medio</td>
                    <td>&lt; 10⁻¹² unità (errore numerico)</td>
                </tr>
                <tr>
                    <td>Errore massimo</td>
                    <td>&lt; 10⁻¹⁰ unità</td>
                </tr>
                <tr>
                    <td>Punti testati</td>
                    <td>100% raggiungibili nel workspace</td>
                </tr>
            </table>
            <p>L'implementazione cinematica è quindi <strong>numericamente accurata</strong>.</p>
        </div>
        
        <h3>8.2 Accuratezza Posizionamento</h3>
        
        <h4>8.2.1 Test Ripetibilità</h4>
        
        <p>La ripetibilità viene valutata comandando il robot di tornare alla stessa posizione più volte:</p>
        
        <div class="code-block">% Test 10 ripetizioni su punto (2.0, 2.0)
n_rep = 10;
target = [2.0, 2.0];
positions = zeros(n_rep, 2);
for i = 1:n_rep
% Vai a posizione casuale
random_pos = [rand()*4+0.5, rand()*4+0.5];
% ... muovi robot ...
% Torna al target
% ... muovi robot a target ...

% Registra posizione finale
positions(i, :) = getCurrentPosition(robot);
end
% Calcola deviazione standard
std_x = std(positions(:, 1));
std_y = std(positions(:, 2));
fprintf('Ripetibilità X: ±%.4f unità\n', std_x);
fprintf('Ripetibilità Y: ±%.4f unità\n', std_y);</div>
        <h4>8.2.2 Accuratezza Disegno Griglia</h4>
        
        <p>La griglia del tris deve rispettare dimensioni precise. Verifica:</p>
        
        <table>
            <tr>
                <th>Elemento</th>
                <th>Dimensione Teorica</th>
                <th>Tolleranza</th>
            </tr>
            <tr>
                <td>Larghezza cella</td>
                <td>0.9 unità</td>
                <td>±0.02 unità</td>
            </tr>
            <tr>
                <td>Altezza cella</td>
                <td>0.9 unità</td>
                <td>±0.02 unità</td>
            </tr>
            <tr>
                <td>Perpendicolarità linee</td>
                <td>90°</td>
                <td>±2°</td>
            </tr>
            <tr>
                <td>Diametro simbolo O</td>
                <td>0.70 unità</td>
                <td>±0.03 unità</td>
            </tr>
        </table>
        
        <div class="note">
            <strong>Osservazione pratica:</strong> Nel robot fisico, l'accuratezza è limitata principalmente da:
            <ul>
                <li>Giochi meccanici nei servomotori (±1-2°)</li>
                <li>Flessibilità dei link sotto carico</li>
                <li>Attrito e slittamento della penna</li>
            </ul>
            La simulazione MATLAB è praticamente esatta (errori &lt; 10⁻¹⁰).
        </div>
    </div>
</div>

<!-- CAPITOLO 9: CONCLUSIONI -->
<div class="page-break">
    <div class="chapter">
        <h2>9. Conclusioni</h2>
        
        <h3>9.1 Risultati Ottenuti</h3>
        
        <p>Il progetto ha raggiunto con successo tutti gli obiettivi prefissati, realizzando un sistema robotico completo e funzionante per il gioco del tris. I risultati principali includono:</p>
        
        <div class="highlight">
            <strong>Aspetti teorici implementati:</strong>
            <ul>
                <li><strong>Modellazione cinematica:</strong> Implementazione completa di cinematica diretta e inversa per manipolatore 2R+P secondo convenzione Denavit-Hartenberg</li>
                <li><strong>Analisi workspace:</strong> Caratterizzazione della regione anulare raggiungibile e verifica posizionamento griglia di gioco</li>
                <li><strong>Jacobiano:</strong> Derivazione analitica per analisi velocità e identificazione singolarità</li>
                <li><strong>Pianificazione moto:</strong> Generazione traiettorie lineari e circolari nello spazio operativo con interpolazione cartesiana</li>
            </ul>
        </div>
        
        <div class="highlight">
            <strong>Aspetti implementativi:</strong>
            <ul>
                <li><strong>Integrazione MATLAB-Arduino:</strong> Protocollo di comunicazione seriale efficiente e robusto</li>
                <li><strong>Controllo tempo reale:</strong> Interpolazione non-bloccante con funzioni di easing per movimenti fluidi</li>
                <li><strong>Algoritmo AI:</strong> Strategia euristica minimax garantisce prestazioni competitive</li>
                <li><strong>Simulazione:</strong> Utilizzo Robotics Toolbox per validazione e generazione video</li>
            </ul>
        </div>
        
        <p>Il sistema è stato testato con successo attraverso:</p>
        <ul>
            <li>Verifica accuratezza cinematica (errori &lt; 10⁻¹⁰ in simulazione)</li>
            <li>Test ripetibilità posizionamento</li>
            <li>Validazione algoritmo AI (100% vittorie/pareggi)</li>
            <li>Registrazione video dell'esecuzione completa</li>
        </ul>
        
        <h3>9.2 Sviluppi Futuri</h3>
        
        <p>Il progetto può essere esteso in diverse direzioni:</p>
        
        <h4>9.2.1 Miglioramenti Algoritmici</h4>
        <ul>
            <li><strong>Minimax completo:</strong> Implementazione algoritmo minimax con ricerca esaustiva dell'albero di gioco per garantire gioco perfetto</li>
            <li><strong>Alpha-Beta Pruning:</strong> Ottimizzazione ricerca per ridurre complessità computazionale</li>
            <li><strong>Apprendimento:</strong> Utilizzo reinforcement learning (Q-learning, Deep Q-Network) per adattamento strategia</li>
        </ul>
        
        <h4>9.2.2 Estensioni Hardware</h4>
        <ul>
            <li><strong>Sensori di forza:</strong> Feedback tattile per controllare pressione penna e rilevare contatto</li>
            <li><strong>Vision system:</strong> Camera per riconoscimento automatico dello stato del gioco</li>
            <li><strong>Servomotori brushless:</strong> Maggiore precisione e dinamica</li>
        </ul>
        
        <h4>9.2.3 Controllo Avanzato</h4>
        <ul>
            <li><strong>Controllo in coppia:</strong> Modello dinamico completo con compensazione gravità e Coriolis</li>
            <li><strong>Controllo adattativo:</strong> Stima parametri on-line per compensare usura e variazioni</li>
            <li><strong>Controllo di forza:</strong> Regolazione pressione penna tramite controllo di impedenza</li>
        </ul>
        
        <h4>9.2.4 Applicazioni Alternative</h4>
        <ul>
            <li>Estensione a giochi più complessi (Forza 4, Dama)</li>
            <li>Utilizzo come plotter generico per disegni artistici</li>
            <li>Piattaforma didattica per insegnamento cinematica e controllo robotico</li>
        </ul>
        
        <div class="note">
            <strong>Considerazioni finali:</strong> Il progetto dimostra come concetti teorici di cinematica, pianificazione del moto e controllo possano essere integrati in un sistema funzionante. L'approccio modulare adottato (separazione cinematica/comunicazione/logica gioco) facilita manutenzione ed estensioni future.
        </div>
    </div>
</div>

<!-- BIBLIOGRAFIA -->
<div class="page-break">
    <div class="chapter">
        <h2>Bibliografia</h2>
        
        <div style="line-height: 2;">
            <p>[1] <strong>Siciliano, B., Sciavicco, L., Villani, L., Oriolo, G.</strong> (2010). <em>Robotics: Modelling, Planning and Control</em>. Springer-Verlag London.</p>
            
            <p>[2] <strong>Corke, P.</strong> (2017). <em>Robotics, Vision and Control: Fundamental Algorithms in MATLAB</em>. Springer International Publishing, 2nd Edition.</p>
            
            <p>[3] <strong>Craig, J. J.</strong> (2017). <em>Introduction to Robotics: Mechanics and Control</em>. Pearson Education, 4th Edition.</p>
            
            <p>[4] <strong>Spong, M. W., Hutchinson, S., Vidyasagar, M.</strong> (2020). <em>Robot Modeling and Control</em>. John Wiley & Sons, 2nd Edition.</p>
            
            <p>[5] <strong>Lynch, K. M., Park, F. C.</strong> (2017). <em>Modern Robotics: Mechanics, Planning, and Control</em>. Cambridge University Press.</p>
            
            <p>[6] <strong>Denavit, J., Hartenberg, R. S.</strong> (1955). "A kinematic notation for lower-pair mechanisms based on matrices". <em>Journal of Applied Mechanics</em>, 22(2), 215-221.</p>
            
            <p>[7] <strong>Paul, R. P.</strong> (1981). <em>Robot Manipulators: Mathematics, Programming, and Control</em>. MIT Press.</p>
            
            <p>[8] <strong>Biagiotti, L., Melchiorri, C.</strong> (2008). <em>Trajectory Planning for Automatic Machines and Robots</em>. Springer-Verlag Berlin Heidelberg.</p>
            
            <p>[9] <strong>Corke, P.</strong> (2023). <em>Robotics Toolbox for MATLAB</em>. Release 10.4. GitHub repository: <code>https://github.com/petercorke/robotics-toolbox-matlab</code></p>
            
            <p>[10] <strong>MATLAB Documentation</strong>. <em>Serial Communication</em>. The MathWorks, Inc. <code>https://www.mathworks.com/help/matlab/serial-port-devices.html</code></p>
            
            <p>[11] <strong>Arduino Reference</strong>. <em>Servo Library</em>. Arduino Documentation. <code>https://www.arduino.cc/reference/en/libraries/servo/</code></p>
            
            <p>[12] <strong>Adafruit Industries</strong>. <em>Adafruit GFX Graphics Library</em>. <code>https://learn.adafruit.com/adafruit-gfx-graphics-library</code></p>
            
            <p>[13] <strong>Russell, S., Norvig, P.</strong> (2020). <em>Artificial Intelligence: A Modern Approach</em>. Pearson, 4th Edition. Chapter 5: Adversarial Search and Games.</p>
            
            <p>[14] Appunti del corso <strong>"Sistemi Robotici"</strong>, Prof. Filippo D'Ippolito, Università degli Studi di Palermo, A.A. 2025/2026.</p>
        </div>
    </div>
</div>
</body>
</html>

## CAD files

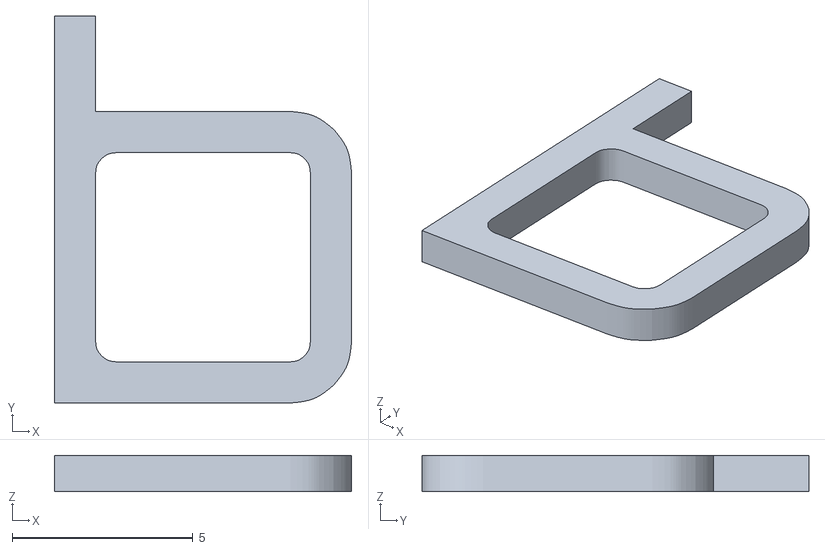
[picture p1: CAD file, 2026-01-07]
file/letter b.stl
8.21 x 10.7 x 1.00

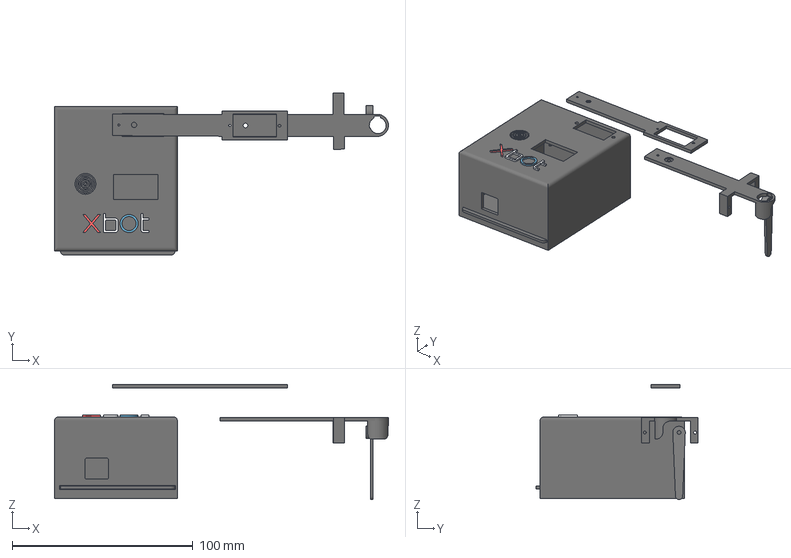
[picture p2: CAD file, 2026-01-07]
file/XbOt.3mf
184.9 x 89.9 x 63.7 mm
Corpo1 x 4
Corpo10
Corpo4
Corpo6
Corpo8
Corpo9

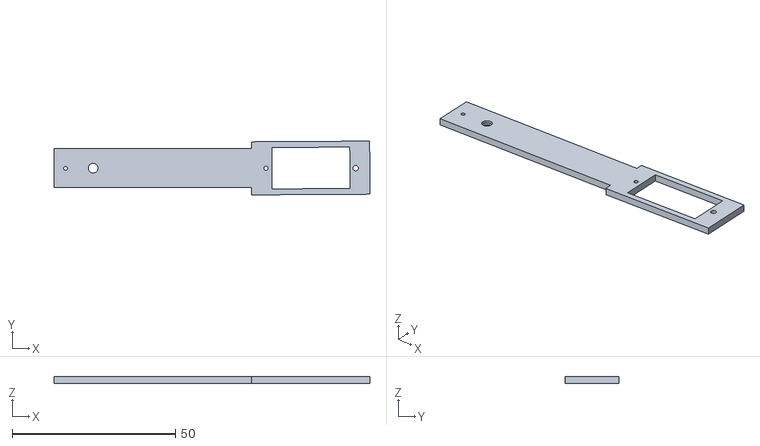
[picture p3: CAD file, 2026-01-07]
file/link 1.stl
96.9 x 16.5 x 2.00

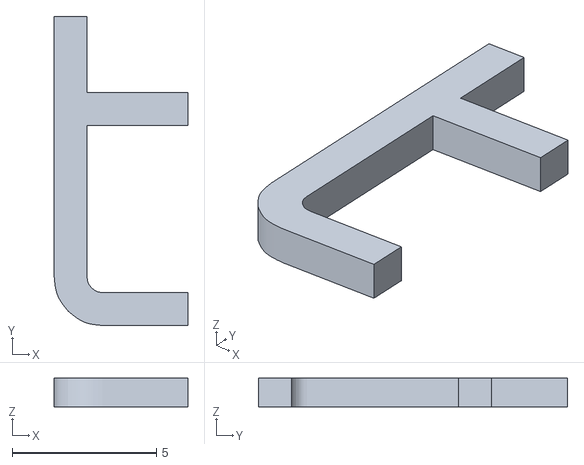
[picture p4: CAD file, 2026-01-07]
file/letter t.stl
4.62 x 10.7 x 1.00

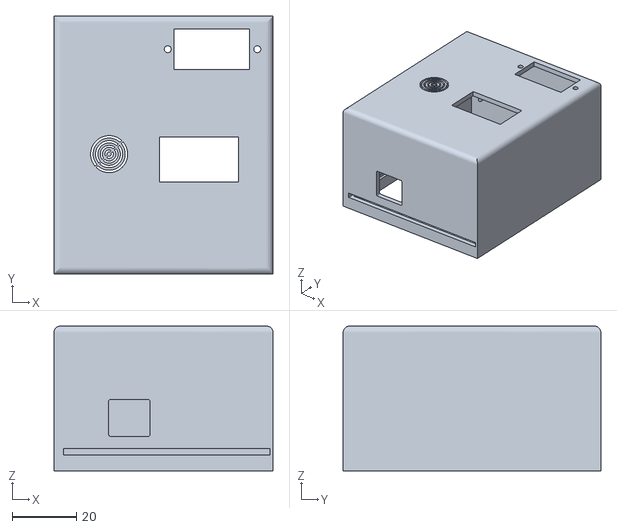
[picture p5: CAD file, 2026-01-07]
file/base.stl
68.0 x 80.0 x 45.0

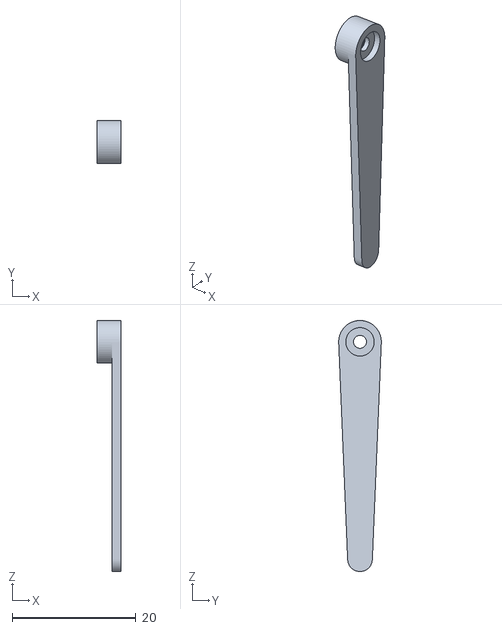
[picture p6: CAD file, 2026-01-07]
file/Support.stl
3.80 x 6.90 x 40.6

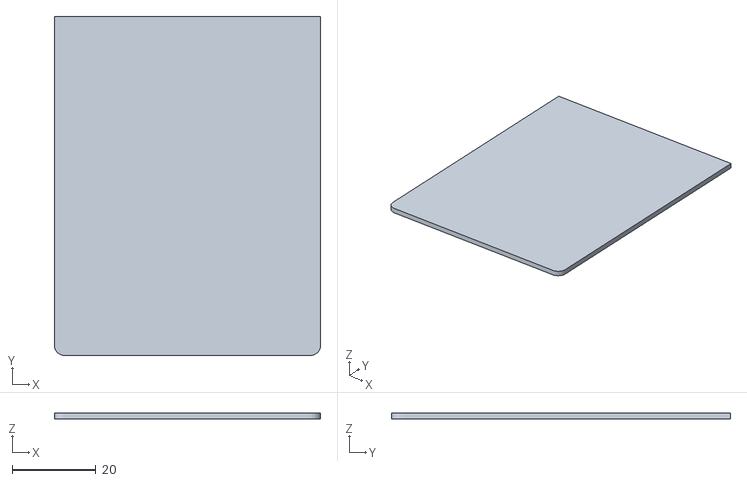
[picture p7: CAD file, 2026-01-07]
file/base 2.stl
63.6 x 80.9 x 1.50

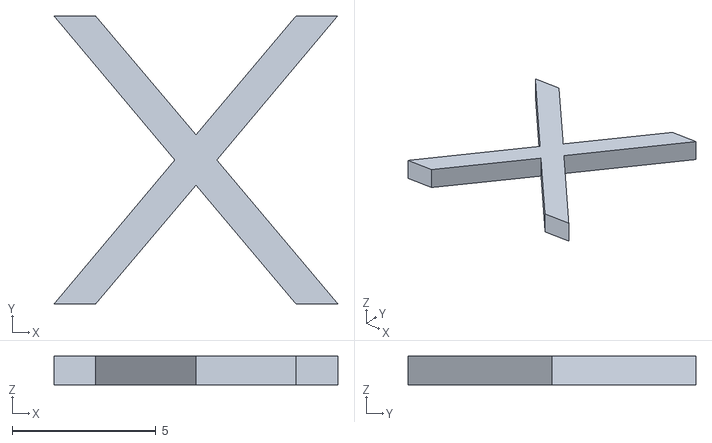
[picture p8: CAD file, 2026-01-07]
file/letter X.stl
9.86 x 10.0 x 1.00

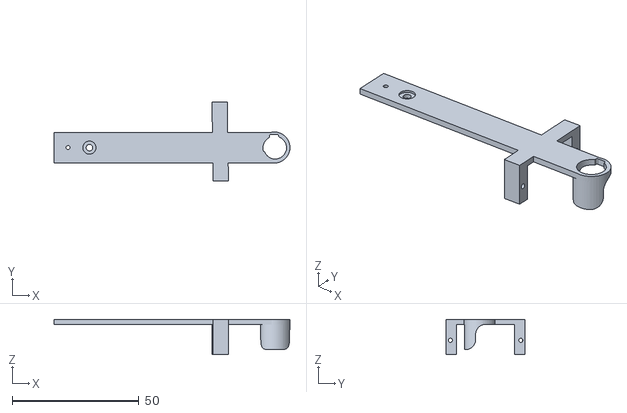
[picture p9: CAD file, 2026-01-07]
file/link 2.stl
93.2 x 31.3 x 14.0

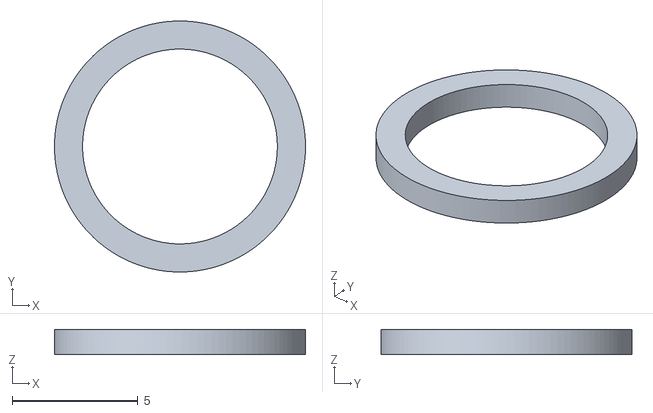
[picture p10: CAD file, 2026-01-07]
file/Letter O.stl
9.99 x 9.99 x 1.00

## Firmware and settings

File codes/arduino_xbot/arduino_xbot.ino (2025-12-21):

#include <Servo.h> //A,90,180,180
#include <Wire.h>
#include <Adafruit_GFX.h>
#include <Adafruit_SSD1306.h>

// --- Servi ---
Servo s1, s2, sp;

// --- Oled --
#define SCREEN_WIDTH 128
#define SCREEN_HEIGHT 64
Adafruit_SSD1306 display(SCREEN_WIDTH, SCREEN_HEIGHT, &Wire, -1);

// --- Pin ---
#define BUZZER_PIN 3
const int PIN_S1 = 9;
const int PIN_S2 = 10;
const int PIN_SP = 11;

// Posizione corrente e target
float cur1 = 90, cur2 = 90, curp = 90;
float target1 = 90, target2 = 90, targetp = 90;

// Posizioni iniziali per interpolazione
float start1 = 90, start2 = 90, startp = 90;

// Timing per interpolazione
unsigned long moveStartMillis = 0;
const unsigned long moveDuration = 500; // tempo per completare il movimento in ms

// =============================================================
// --- OLED Helper ---
// --- Stato logo ---
bool logoShown = true;   // all'inizio sì

void Logo(){
  display.clearDisplay(); 
  display.setTextSize(2.5); 
  display.setTextColor(SSD1306_WHITE); 
  display.setCursor(10, 25); 
  display.println("XBOT v1.0"); display.display();
}

void showMessage(String msg, int x, int y, float z) {
  display.clearDisplay();
  display.setTextSize(z);
  display.setTextColor(SSD1306_WHITE);
  display.setCursor(x, y);
  display.println(msg);
  display.display();
}


// =============================================================
// --- Musiche ---
void playStartup() {
  int melody[] = {262, 294, 330, 392};
  int duration[] = {150, 150, 150, 300};
  for (int i = 0; i < 4; i++) {
    tone(BUZZER_PIN, melody[i], duration[i]);
    delay(duration[i] + 50);
  }
}

void playWin() {
  int melody[] = {392, 440, 494, 523, 494, 523, 587};
  int duration[] = {150, 150, 150, 200, 150, 200, 400};
  for (int i = 0; i < 7; i++) {
    tone(BUZZER_PIN, melody[i], duration[i]);
    delay(duration[i] + 30);
  }
}

void playGameOver() {
  // Note in Hz
  int melody[] = {165, 147, 131, 110}; // Mi3, Re3, Do3, La2
  int duration[] = {700, 700, 700, 1800}; // prime 3 lente, ultima molto lunga
  
  for (int i = 0; i < 4; i++) {
    tone(BUZZER_PIN, melody[i], duration[i]);
    delay(duration[i] + 100); // pausa tra le note
    noTone(BUZZER_PIN);
  }
}

void playMove() {
  tone(BUZZER_PIN, 440, 80);
  delay(100);
}

// =============================================================

void setup() {
  Serial.begin(115200);

  // OLED
  if (!display.begin(SSD1306_SWITCHCAPVCC, 0x3C)) {
    for (;;);
  }
  display.clearDisplay();
  Logo();  

  s1.attach(PIN_S1);
  s2.attach(PIN_S2);
  sp.attach(PIN_SP);

  // Imposta posizioni iniziali dei servo
  cur1 = 90;
  cur2 = 180;
  curp = 90;
  s1.write(cur1);
  s2.write(cur2);
  sp.write(curp);

 playStartup();   // Musica all'accensione

  // --- Comando iniziale A,90,180,90 ---
  start1 = cur1;
  start2 = cur2;
  startp = curp;

  target1 = 90;
  target2 = 180;
  targetp = 90;

  moveStartMillis = millis();
}

void loop() {
  // 1️⃣ Leggi seriale in modo non bloccante
  if (Serial.available()) {
    String line = Serial.readStringUntil('\n');
    line.trim();
    if (line.length() > 0 && line.charAt(0) == 'A') {
      int a1=90, a2=180, ap=0;
      if (sscanf(line.c_str(),"A,%d,%d,%d",&a1,&a2,&ap) == 3) {
        start1 = cur1;
        start2 = cur2;
        startp = curp;

        target1 = constrain(a1, 0, 180);
        target2 = constrain(a2, 0, 180);
        targetp = constrain(ap, 0, 180);

        moveStartMillis = millis();
      }
    }
    else if (line.startsWith("MOVE")) {
      playMove();
    }
    else if (line.startsWith("WIN")) {
      playWin();
    }
    else if (line.startsWith("LOSE")) {
      playGameOver();
    }
    else if (line.startsWith("MSG,")) {
      // Trova le ultime 3 virgole
      int lastComma = line.lastIndexOf(',');
      int secondLast = line.lastIndexOf(',', lastComma - 1);
      int thirdLast = line.lastIndexOf(',', secondLast - 1);

      // Messaggio fino alla terza virgola
      String msg = line.substring(4, thirdLast);

      // Coordinate e dimensione
      int x = line.substring(thirdLast + 1, secondLast).toInt();
      int y = line.substring(secondLast + 1, lastComma).toInt();
      float z = line.substring(lastComma + 1).toInt();

      showMessage(msg, x, y, z);
    }
  }

  unsigned long now = millis();
  float t = float(now - moveStartMillis) / moveDuration;
  t = constrain(t, 0.0, 1.0); // Assicura che non si superi il 100%

  // Ottieni il fattore di movimento "curvato" dalla funzione
  float eased = easeInOut(t);

  // Calcola la nuova posizione interpolata
  // Formula: Posizione = Partenza + (DistanzaTotale * FattoreEased)
  cur1 = start1 + (target1 - start1) * eased;
  cur2 = start2 + (target2 - start2) * eased;
  curp = startp + (targetp - startp) * eased;

  // Invia il comando ai servomotori
  s1.write(round(cur1));
  s2.write(round(cur2));
  sp.write(round(curp));

  delay(10); // loop veloce ma non al massimo della CPU
}

// Funzione di easing in-out per movimento fluido
float easeInOut(float t) {
  // Se t < 0.5 (prima metà): Accelera con formula 2*t^2
  // Se t >= 0.5 (seconda metà): Decelera invertendo la parabola
  return t<0.5 ? 2*t*t : -1 + (4 - 2*t)*t;
}
